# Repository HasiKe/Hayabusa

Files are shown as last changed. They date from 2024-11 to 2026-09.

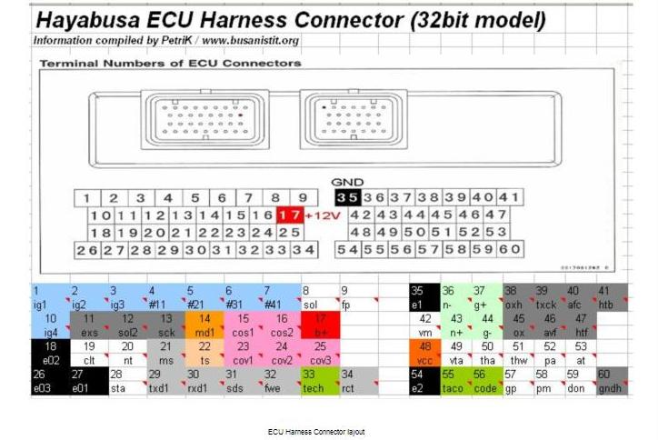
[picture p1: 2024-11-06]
hardware/ECU/docs/Hayabusa ECU 1.jpg

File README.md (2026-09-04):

# Hayabusa

Eigenbau-Motorsteuerung und Umbauprojekte für die Suzuki Hayabusa der ersten
Generation (1999–2007).

Das Repository enthält die Elektronik des Umbaus: Schaltpläne und Layouts der
Steuergeräte, die Firmware, die Abstimmung und die Dokumentation dazu. Die
Speeduino-Firmware ist dabei der Ausgangspunkt, nicht das Ergebnis — Platinen,
Sensorik und die Motorrad-spezifischen Funktionen sind eigene Arbeit.

---

## Inhalt

| Pfad | Inhalt |
|---|---|
| [`hardware/ECU/`](hardware/ECU) | Steuergerät: Schaltplan, Layout, Fertigungsdaten, Gehäuse |
| [`speeduino/`](https://github.com/HasiKe/speeduino/tree/Hayabusa/ECU-R3) | Motorsteuerungs-Firmware und Sensor-Modul-Firmware, Submodul auf den eigenen Fork |
| [`hardware/exhaust-mic/`](hardware/exhaust-mic) | Zweikanalige Tonaufnahme von Motor und Auspuff |
| [`tune/`](tune) | TunerStudio-Projekt [`Hayabusa-R3`](tune/Hayabusa-R3) (generiert aus den Serienkennfeldern in `tune/setup/`) |
| [`docs/`](docs) | Dokumentation und Spezifikationen |

---

## Das Steuergerät

Ersetzt das Seriensteuergerät vollständig. Zweilagige Platine von rund
148 × 112 mm mit einem Teensy 4.1 als Rechenkern, Schaltplanstand
**Revision 3.0 (Entwurf)**.

### Leistungsteil

| Baustein | Aufgabe |
|---|---|
| MC33810 | Einspritzung und Zündung über SPI, vier Kanäle je Pfad |
| 4× ISL9V5036 | Zünd-IGBTs an den Gate-Treibern des MC33810 |
| 3× ZXMS6006 | Low-Side für Kraftstoffpumpe, Lüfter, Starter, Drehzahlmesser, FI-Lampe |
| 2× BTF3050TE | High-Side für Ladedrucksteller und Lambdaheizung, mit Stromfühler |
| DRV8434A | Schrittmotor für den Leerlaufsteller |

### Signalaufbereitung

| Baustein | Aufgabe |
|---|---|
| MAX9926 | Zwei Kanäle Induktivgeber für Kurbelwelle und Nockenwelle |
| TPIC8101 | Klopfsensor mit programmierbarem Bandpass und Integrator |
| LMV324 | Puffer für Lambda, Komparator für den Kippschalter |
| SP720 / BAV199 | Klemmung sämtlicher Sensoreingänge |

### Versorgung und Infrastruktur

| Baustein | Aufgabe |
|---|---|
| LM74700 + SQM120N06 | Verpolschutz als aktive Diode |
| TPS54360B | Abwärtswandler auf 5 V, automotive-tauglich |
| TPS3823 | Externer Watchdog, verriegelt bei Ausfall die Endstufen |
| W25Q32 | SPI-Flash als Kennfeldspeicher |
| MCP2562 | CAN zum Sensor-Modul und zum Cockpit |
| ADXL343 | Beschleunigungssensor, bestückt, softwareseitig ungenutzt |

Vollständige Pinbelegung, Kalibrierhinweise und die offenen Punkte der
Revision 3.0: **[HAYABUSA_ECU_R3.md](https://github.com/HasiKe/speeduino/blob/Hayabusa/ECU-R3/HAYABUSA_ECU_R3.md)**

---

## Firmware

Fork von [Speeduino](https://github.com/speeduino/speeduino), Branch
[`Hayabusa/ECU-R3`](https://github.com/HasiKe/speeduino/tree/Hayabusa/ECU-R3),
eingebunden als Submodul.

```bash
git submodule update --init
cd speeduino && pio run -e teensy41_hayabusa
```

In TunerStudio Board **57 „Gen1 Hayabusa ECU R3"** wählen.

Was über den Serienstand von Speeduino hinausgeht:

- **Vier umschaltbare Kennfeldsätze** für Kraftstoff, Zündung und Ladedruck.
  Auswahl beim Einschalten über Kupplung und Vollgas, Rückmeldung über
  FI-Lampe und Drehzahlmesser.
- **Klopfregelung** mit dem TPIC8101: Konfiguration über SPI,
  Integrationsfenster am Zündfunken, Auswertung über Speeduinos
  Zündrücknahme.
- **Externer Watchdog**, der nur bedient wird, solange die Hauptschleife
  läuft — bleibt sie hängen, fallen Einspritzung und Zündung ab.
- **Motorrad-Ein- und Ausgänge**: Neutral, Kupplung, Gangsensor,
  Kippschalter, FI-Lampe, Lambdaheizung.
- **Kanalzuordnung nach Zündfolge 1-2-4-3** am Serienstecker, der nach
  Zylindern belegt ist.
- **Kennfelder im SPI-Flash** statt in der EEPROM-Emulation des Teensy, die
  für vier Sätze zu klein ist.

---

## Sensor-Modul

Zweite Platine, 120 × 64 mm, eigener STM32G474. Nimmt der Motorsteuerung alles
ab, was langsam ist, und meldet es über CAN.

- vier Abgastemperaturen über MAX31855K-Thermoelementwandler
- Öldruck, Kraftstoffdruck, Abgasdruck, Öltemperatur
- zwei Wassertemperaturen im Ladeluftkühlerkreis
- Quickshifter-Geber
- Regelung des Ladeluftkühler-Lüfters, lokal und damit unabhängig vom CAN-Bus

Firmware, CAN-Protokoll und die Zuordnung zu Speeduinos Eingangskanälen:
[`speeduino/sensor-module/README.md`](https://github.com/HasiKe/speeduino/blob/Hayabusa/ECU-R3/sensor-module/README.md)

---

## Exhaust-Mic

Eigenständiges Projekt: zweikanalige Tonaufnahme von Motor- und
Auspuffgeräuschen. Zwei Mikrofonköpfe mit 135 dBSPL Grenzschalldruck an einem
24-bit-Stereo-ADC, aufgezeichnet von einem ESP32-S3 auf microSD, mit
Zeitstempeln zur Synchronisation mit Videomaterial.

Schaltpläne, Layout, Gehäuse und Firmware entstehen aus Python-Generatoren —
Pinbelegung und Netznamen stehen dadurch nur an einer Stelle.

Eigenes Repository, hier als Submodul eingebunden:
[HasiKe/Exhaust-Mic](https://github.com/HasiKe/Exhaust-Mic)

---

## Stand

| Bereich | Stand |
|---|---|
| Steuergerät, Schaltplan | Revision 3.0 im Entwurf, Revision 1 gefertigt |
| Steuergerät, Firmware | Läuft, auf aktuellem Speeduino-Stand |
| Sensor-Modul, Hardware | Revision 3.0 im Entwurf |
| Sensor-Modul, Firmware | Übersetzt, noch nicht am Fahrzeug erprobt |
| Exhaust-Mic | Schaltplan und Layout fertig, Fertigung offen |
| Grundabstimmung | Erststart-Tune erzeugt (`tune/Hayabusa-R3`), Motor damit noch nicht gelaufen |

Was vor dem ersten Start geprüft werden muss — Trigger-Winkel, Kalibrierungen,
Kanalzuordnung, Polarität des Kippschalters, Klopfschwellen — steht in
[`tune/Hayabusa-R3/README.md`](tune/Hayabusa-R3/README.md),
[HAYABUSA_ECU_R3.md](https://github.com/HasiKe/speeduino/blob/Hayabusa/ECU-R3/HAYABUSA_ECU_R3.md)
und im [README des Sensor-Moduls](https://github.com/HasiKe/speeduino/blob/Hayabusa/ECU-R3/sensor-module/README.md).

---

## Dokumentation

| Dokument | Inhalt |
|---|---|
| [HARDWARE.md](docs/HARDWARE.md) | Platinen, Steckerbelegung, mechanische Daten |
| [SOFTWARE.md](docs/SOFTWARE.md) | Firmware-Aufbau, Build, Codestruktur |
| [INSTALLATION.md](docs/INSTALLATION.md) | Einbau, Verkabelung, Inbetriebnahme |
| [TUNING.md](docs/TUNING.md) | Kennfelder, Kalibrierung, Abstimmung |
| [PROJECT_STRUCTURE.md](docs/PROJECT_STRUCTURE.md) | Aufbau des Repositories |
| [CHANGELOG.md](CHANGELOG.md) | Versionshistorie |

Externe Quellen: [Speeduino-Wiki](https://wiki.speeduino.com) ·
[Speeduino-Forum](https://speeduino.com/forum) ·
[TunerStudio](http://tunerstudio.com)

---

## Lizenz

Die Firmware im Submodul steht unter GPL v3, wie Speeduino selbst. Hardware
und Dokumentation stehen unter CC BY-SA 4.0. Fremdsoftware liegt nicht im
Repository, sondern wird bei Bedarf aus der jeweiligen Quelle geladen.

## Haftungsausschluss

Ein selbst gebautes Steuergerät greift in Zündung und Kraftstoffzufuhr ein.
Fehler darin führen zu Motorschaden oder zum Ausfall während der Fahrt. Der
Nachbau erfolgt auf eigene Verantwortung, und im Geltungsbereich der StVZO
erlischt mit solchen Eingriffen die Betriebserlaubnis, solange kein Gutachten
vorliegt.

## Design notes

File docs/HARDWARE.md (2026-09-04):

# Hardware-Dokumentation

Steuergerät **Gen1 Hayabusa ECU Rev 3.0** (Schaltplan und Layout in `hardware/ECU/`,
Fertigungsdaten in `hardware/ECU/output/pcbway/`, Stückliste in `hardware/ECU/bom/`).
Die Rev 1 auf Dropbear-Basis ist Geschichte; dieses Dokument beschreibt nur die Rev 3.

## Überblick

| Parameter | Wert |
|---|---|
| Rechenkern | Teensy 4.1 (NXP i.MX RT1062, 600 MHz), USB über J2 auf die Device-Pads |
| Platine | zweilagig, ca. 148 × 112 mm, drei M3-Befestigungen, Gehäuse in `hardware/ECU/case/` (Fusion 360, STL, Kühlkörper) |
| Stecker | J2 = TE 6437288-3, 60-polig, Belegung nach dem Serien-Steuergerät (`hardware/ECU/docs/Pinout.ods`, Blatt `Pinout_ori_ECU`) |
| Endstufen | MC33810 (SPI, GPGD-Modus) → 4 Low-Side-Injektortreiber, 4 Gate-Treiber für ISL9V5036-IGBTs |
| Kleinlasten | 3× ZXMS6006 Low-Side (Kraftstoffpumpe, Lüfter, Starter, Drehzahlmesser, FI-Lampe, Spare), 2× BTF3050TE High-Side (Ladedrucksteller, Lambdaheizung) |
| Leerlaufsteller | DRV8434A Schrittmotortreiber (Serienmotor hat keinen, Ausgang ungenutzt) |
| Kurbel/Nocke | MAX9926, zwei VR-Kanäle |
| Klopfen | TPIC8101 über SPI, Integratorausgang an A17 |
| Lambda | LMV324-Puffer 0–3,3 V, kein Breitband-Frontend (Innovate LC-2 extern) |
| Versorgung | LM74700 + SQM120N06 (Verpolschutz), TPS54360B (5 V Buck), LD1117S33 (3,3 V), TPS7B6950-Q1 (VDDA, Sensor-5 V an J2.48) |
| Watchdog | TPS3823, WDI von D3, RESET verriegelt über 74LVC1G00 mit D2 den MC33810-OUTEN |
| Speicher | W25Q32 SPI-Flash als Kennfeldspeicher (8184 Byte emuliertes EEPROM, 4 Kennfeldsätze) |
| Kommunikation | MCP2562 CAN (CAN1, 500 kbit/s) zum Sensor-Modul, Serial1 auf J1 |
| Sonstiges | ADXL343 bestückt, softwareseitig ungenutzt |

## Teensy-Belegung

Aus der Rev-3.0-Netzliste, identisch mit `speeduino/HAYABUSA_ECU_R3.md`.

| Teensy | Netz / Baustein | Firmware |
|---|---|---|
| D0 / D1 | J1 | Serial1 (sekundäre Schnittstelle) |
| D2 | 74LVC1G00 → MC33810 OUTEN | Ausgabefreigabe, Fuel- und Spark-Kill |
| D3 | TPS3823 WDI | Watchdog |
| D4 | J2.20 | Neutralschalter |
| D5 | IC3.1 → J2.9 | Kraftstoffpumpe |
| D6 | W25Q32 CS | Kennfeldspeicher |
| D7 | ADXL343 CS | ungenutzt |
| D8 | IC3.2 → J2.55 | Drehzahlmesser |
| D9 | DRV8434A nFAULT + BTF3050 Status | Treiberfehler, aktiv low |
| D10 | MC33810 CS | Injektor- und Zündtreiber |
| D11 / D12 / D13 | MOSI / MISO / SCLK | gemeinsamer SPI-Bus |
| D20 | MAX9926 COUT1 | Kurbelwelle |
| D21 | MAX9926 COUT2 | Nockenwelle |
| D22 / D23 | MCP2562 | CAN1 |
| D24 | U13 → J2.30 | Ladedrucksteller |
| D25 | U14 → J2.46 | Lambdaheizung (bei LC-2 offen lassen) |
| D26 | IC2.2 → J2.28 | Starter-Ausgang, frei für programmierbaren Ausgang |
| D27 | IC2.1 → J2.42 | FI-Lampe |
| D28 | IC4.2 → J2.47 | Spare-Ausgang |
| D29 | IC4.1 → J2.29 | Lüfter |
| D30 / D31 / D32 | DRV8434A STEP / DIR / ENABLE+nSLEEP | Schrittmotor |
| D33 | J2.19 | Kupplung: Launch-Eingang und Kennfeldwahl |
| D34 | LMV324-Komparator | Kippschalter |
| D35 | J2.60 | Spare-Digitaleingang, als VSS gemappt |
| D36 / D37 | TPIC8101 INT/HOLD / CS | Klopfsensor-IC |
| A0 / A1 / A2 | J2.58 / J2.52 / J2.49 | MAP / Baro / TPS |
| A3 | J2.38 über LMV324 | Lambda |
| A4 / A5 | J2.50 / J2.51 | IAT / CLT |
| A14 / A15 | J2.39 / 12V-PROT-Teiler | Flex / Batteriespannung |
| A16 | J2.57 | Gangsensor |
| A17 | TPIC8101 OUT | Klopfintegrator |

## Steckerbelegung J2

Die Nummern entsprechen dem Serien-Steuergerät, der Serienkabelbaum passt. Nur die
Pins mit Funktion in der Rev 3 sind gelistet.

| Pin | Serie | Rev 3 | Anmerkung |
|---|---|---|---|
| 1 | Spule Zyl. 1 | IGN1 (GD0, Q2) | Kanalzuordnung siehe unten |
| 2 | Spule Zyl. 2 | IGN2 (GD1, Q1) | |
| 3 | Spule Zyl. 3 | IGN4 (GD2, Q3) | Speeduino-Kanal 4 = vierter in der Zündfolge |
| 10 | Spule Zyl. 4 | IGN3 (GD3, Q4) | Speeduino-Kanal 3 = dritter in der Zündfolge |
| 7 | Düse Zyl. 1 | INJ1 (OUT0) | |
| 6 | Düse Zyl. 2 | INJ2 (OUT1) | |
| 5 | Düse Zyl. 3 | INJ4 (OUT2) | |
| 4 | Düse Zyl. 4 | INJ3 (OUT3) | |
| 8, 31, 32, 45 | 8: VC-Solenoid | Schrittmotor A1/A2/B1/B2 | ungenutzt |
| 9 | Kraftstoffpumpe | Low-Side D5 | |
| 17 | Zündung 12 V | 12V-PROT | Versorgung |
| 18, 26, 27, 35 | Masse | GND | |
| 19 | Starterrelais-Eingang | Kupplung (D33) | 12 V bei Starter, 0 V bei gezogener Kupplung; siehe Befund 1 |
| 20 | Neutral | D4 | 0 V in Neutral |
| 22 | Diagnose | DIAG-IN | nicht verbunden |
| 28 | Starterrelais | Starter-Ausgang D26 | |
| 29 | – | Lüfter D29 | |
| 30 | – | Ladedrucksteller D24 | |
| 36 / 43 | Kurbel − / + | MAX9926 Kanal 1 | VR |
| 37 / 44 | Nocke + / − | MAX9926 Kanal 2 | VR |
| 38 | – | Lambda 0–3,3 V | LC-2 Analogausgang 1 |
| 39 | – | Flex | 2,2 kΩ Pull-up, ungenutzt |
| 42 | Kraftstoff 12 V | FI-Lampe D27 | |
| 46 | – | Lambdaheizung D25 | offen lassen |
| 47 | – | Spare-Ausgang D28 | |
| 48 | Sensor 5 V | VDDA | TPS7B6950, Polyfuse 150 mA |
| 49 | TPS | A2 | |
| 50 | Ansauglufttemperatur | A4 | |
| 51 | Wassertemperatur | A5 | |
| 52 | Atmosphärendruck | A1 (Baro) | im Tune nicht genutzt |
| 53 | – | Spare-Analog | Beschaltung vorhanden, kein ADC-Pin (Befund 2) |
| 54 | Sensormasse | GNDA | |
| 55 | Drehzahlmesser | D8 | |
| 57 | Gangsensor | A16 | 1 kΩ Vorwiderstand, Schwellen in der Firmware |
| 58 | Saugrohrdruck | A0 (MAP) | Serien-IAP 18590-81A00 |
| 59 | Kippschalter | Komparator → D34 | |
| 60 | – | Spare-Digital D35 | |
| 14 / 15 | – | CAN H / L | Sensor-Modul, Cockpit |
| 16 / 24 | Diagnose | USB VBUS / USB GND | USB-Daten siehe Blatt Comms |

### Kanal- und Zylinderzuordnung

Speeduino feuert seine Kanäle in der Zündfolge (0°, 180°, 360°, 540°), der Stecker ist
nach Zylindernummer belegt, die Zündfolge ist 1-2-4-3. Die Firmware legt deshalb Kanal 3
auf Zylinder 4 und Kanal 4 auf Zylinder 3 (`getHayabusaR3Mapping()`); am Kabelbaum wird
nichts getauscht. Zylinder 1 liegt links auf der Generatorseite.

## Analoge Eingangsbeschaltung

| Eingang | Beschaltung | Folge für die Kalibrierung |
|---|---|---|
| MAP, Baro, TPS, Gangsensor | 470 Ω → 100 nF → Teiler 12 k/20 k (0,625) → 10 nF → BAV199 an 3V3/GND | ADC-Vollausschlag = 3,3 V / 0,625 = 5,28 V am Sensor. `mapMax` entsprechend rechnen (Serien-IAP: 10 / 142 kPa) |
| IAT, CLT | Pull-up 2,49 kΩ an **3V3** → 470 Ω → BAV199 | ratiometrisch zur ADC-Referenz, TunerStudio-Bias 2490 Ω exakt |
| Lambda | LMV324-Folger an 3,3 V | Sensor 0–3,3 V, LC-2 Ausgang entsprechend programmieren |
| Batterie | 47 k/10 k von 12V-PROT | Vollausschlag 18,8 V; Firmware skaliert für Board 57 |
| Flex | 2,2 kΩ Pull-up 3V3, 1 kΩ + 1 nF + BAV199 | Frequenzeingang |
| Neutral, Kupplung, Spare-Digital | Teiler 10 k/10 k zwischen Steckerpin und 3V3 (R78/R80, R71/R73, R79/R81), 100 nF, BAV199 | geschlossener Schalter ergibt nur 1,65 V, siehe Befund 1 |
| Kippschalter | LMV324 als Komparator, Schwelle 1,2 V nach Teiler 0,5 | Polarität am Fahrzeug prüfen |

Kurbel und Nocke: MAX9926 datenblattkonform, differenziell bis zum IC, Serienwiderstände
vor den Teensy-Pins, Eingangsfilter 470 pF. Trigger-Flanke RISING.

## Klopfsensor

TPIC8101 am SPI, Konfiguration beim Start durch die Firmware: 4-MHz-Resonator, Kanal 1,
Bandpass Index 39 (6,37 kHz, erste Umfangsmode einer 81-mm-Bohrung), Verstärkung Index 14,
Integrator Index 18 (200 µs). Fenster öffnet mit dem Zündfunken, schließt aus dem
1-kHz-Dienst. Bosch 0 261 231 173 am Block zwischen Zylinder 2 und 3 geplant, noch nicht
verbaut. In TunerStudio Klopfmodus **Analog**, der Pin wird ignoriert.

## Befunde der Rev 3.0

Aus `speeduino/HAYABUSA_ECU_R3.md`, hardwareseitig noch offen:

1. **Schalteingänge erreichen keinen gültigen Low-Pegel.** Neutral (D4), Kupplung (D33)
   und Spare-Digital (D35) liegen über 10 k/10 k zwischen Stecker und 3V3; geschlossener
   Schalter ergibt 1,65 V, Teensy VIL ist 0,9 V. Kennfeldwahl und Launch-Eingang hängen
   davon ab. Abhilfe: unteren Zweig nach Masse oder 10 k in Serie mit 100 k Pull-up.
2. **Spare-Analog (J2.53) endet an keinem ADC-Pin.**
3. **Kein Startanforderungs-Eingang**, deshalb keine Neutral/Kupplungs-Verriegelung; der
   Starter-Ausgang bleibt frei nutzbar.

Unkritisch: MC33810 FB0..3 und RSP werden im GPGD-Modus nicht benutzt; die GIN-Pins sind
nicht angeschlossen, die Spulen werden über SPI geschaltet.

## Stückliste und Fertigung

- `hardware/ECU/bom/ECU-BOM.csv` (107 Positionen) und `Sensor-Modul-BOM.csv` (46), alle
  Bauteile mit Hersteller- und DigiKey-Nummer.
- PCBWay-Pakete (Gerber, CPL, BOM) in `hardware/ECU/output/pcbway/<board>/`.
- Last-Time-Buy-Teile: MCZ33810EK und ZXMS6006DT8TA (2027), Vorrat kaufen.
- Bestellungen und Fahrzeugteile: `docs/BESTELLUNG.ods`.

## Sensor-Modul

Zweite Platine, 120 × 64 mm, STM32G474, Rev 3.0. Vier Abgastemperaturen (MAX31855K),
Öl-, Kraftstoff- und Abgasdruck, Öltemperatur, zwei Wassertemperaturen im
Ladeluftkühlerkreis, Quickshifter-Geber, lokale Regelung des Ladeluftkühler-Lüfters.
Meldet über CAN an die ECU. Schaltplan `hardware/ECU/sensor-module.kicad_sch`, Firmware
und CAN-Protokoll in `speeduino/sensor-module/`.

## Externe Sensorik am Fahrzeug (1999)

| Sensor | Teil | Kennwerte |
|---|---|---|
| Saugrohrdruck | Serien-IAP 18590-81A00 an J2.58 | ≈ 3,6 V bei 100 kPa, Näherung P ≈ 25·V + 10 kPa |
| TPS | Serie | ≈ 1,1 V geschlossen, 4,3 V offen |
| Kühlmittel | Serien-NTC | 2,3–2,6 kΩ bei 20 °C, 811 Ω bei 50 °C, 318 Ω bei 80 °C |
| Ansaugluft | Serien-NTC | 2,2–2,7 kΩ bei 20 °C |
| Kurbelwelle | VR im Generatordeckel, 8 Zähne gleichmäßig auf dem Generatorrotor | 180–280 Ω |
| Nockenwelle | VR auf dem Ventildeckel links, ein Stift auf der Einlassnocke | 0,9–1,3 kΩ |
| Lambda | Innovate LC-2 + Bosch LSU 4.9 | Analogausgang 1 auf 0–3,3 V programmiert |
| Düsen | 15710-24F00, Keihin, hochohmig 11–16 Ω | ≈ 257 cc/min bei 3 bar (Annahme) |
| Spulen | Denso 33410-24F00 Stabspulen ohne Igniter | 0,8–1,2 Ω primär |

---

**Version**: 4.0
**Stand**: September 2026

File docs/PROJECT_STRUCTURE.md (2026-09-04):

# Projektstruktur

## Verzeichnisübersicht

```
hayabusa/
├── README.md                     Projektübersicht
├── CHANGELOG.md                  Versionshistorie
├── .gitmodules                   drei Submodule
│
├── docs/                         Dokumentation
│   ├── HARDWARE.md               Steuergerät Rev 3, Stecker, Eingangsbeschaltung
│   ├── SOFTWARE.md               Firmware-Fork, Board 57, TunerStudio, Generator
│   ├── INSTALLATION.md           Einbau, Verkabelung, Inbetriebnahme
│   ├── TUNING.md                 Kennfelder, Kalibrierung, Abstimmung
│   ├── PROJECT_STRUCTURE.md      diese Datei
│   ├── BESTELLUNG.ods            Bestell- und Teilelisten
│   ├── Berechnungen.ods          Auslegungsrechnungen
│   ├── Drehmoment.pdf            Anzugsdrehmomente, dazu ARP- und Wössner-Anleitungen
│   ├── Speeduino_manual.pdf      Speeduino-Handbuch
│   └── explosionszeichnung/      Suzuki-Ersatzteilzeichnungen
│
├── hardware/                     nur die beiden Elektronikprojekte
│   ├── ECU/                      Steuergerät und Sensor-Modul (KiCad)
│   │   ├── *.kicad_*             Schaltpläne und Layouts beider Platinen
│   │   ├── bom/                  Stücklisten (CSV): ECU 107, Sensor-Modul 46 Positionen
│   │   ├── case/                 Gehäuse (Fusion 360, STL, Kühlkörper)
│   │   ├── datasheets/           Datenblätter der Hauptbausteine
│   │   ├── docs/                 Pinout.ods (Serienstecker), Kabelplan, Altunterlagen
│   │   ├── lib/                  Symbole, Footprints, 3D — teensy.pretty als Submodul
│   │   └── output/               Schaltplan-PDFs, Gerber, STEP; Fertigungspakete in pcbway/
│   └── exhaust-mic/              Submodul HasiKe/Exhaust-Mic
│
├── speeduino/                    Submodul HasiKe/speeduino, Branch Hayabusa/ECU-R3
│   ├── speeduino/                Firmware, src/hayabusa/ für die Board-Funktionen
│   ├── reference/speeduino.ini   TunerStudio-Definition
│   ├── sensor-module/            STM32G474-Firmware des Sensor-Moduls
│   ├── HAYABUSA_ECU_R3.md        Firmware-Notizen zur Rev 3
│   └── platformio.ini            Umgebung teensy41_hayabusa
│
└── tune/
    ├── Hayabusa-R3/              TunerStudio-Projekt (generiert)
    │   ├── CurrentTune.msq
    │   ├── README.md             Herkunft, Checkliste vor dem ersten Start
    │   ├── projectCfg/           mainController.ini (Kopie der Fork-INI), project.properties
    │   └── tools/                gen_tune.py und Helfer
    └── setup/                    Serienkennfelder (maps.ods), ECUeditor-Screenshot
```

## Architektur

### Hardware

```
┌─────────────────────────────────────────────────────────────┐
│                        HARDWARE                              │
├─────────────────────────────────────────────────────────────┤
│  ┌─────────────┐    ┌─────────────┐    ┌─────────────┐      │
│  │  Sensoren   │    │  ECU Board  │    │  Aktuatoren │      │
│  │             │    │             │    │             │      │
│  │  TPS        │◄──►│  Teensy 4.1 │◄──►│  Injektoren │      │
│  │  MAP        │    │  Speeduino  │    │  Zündung    │      │
│  │  CLT/IAT    │    │  MC33810    │    │  Kraftstoff │      │
│  │  O2 (LC-2)  │    │  CAN        │    │  Lampe/Tach │      │
│  │  RPM/Cam    │    │             │    │             │      │
│  └─────────────┘    └─────────────┘    └─────────────┘      │
└─────────────────────────────────────────────────────────────┘
```

### Software

```
┌─────────────────────────────────────────────────────────────┐
│                      SOFTWARE STACK                          │
├─────────────────────────────────────────────────────────────┤
│  ┌─────────────┐    ┌─────────────┐    ┌─────────────┐      │
│  │ TunerStudio │    │  Speeduino  │    │  Hardware   │      │
│  │             │    │  Firmware   │    │  Treiber    │      │
│  │  GUI        │◄──►│  Engine     │◄──►│  PWM/ADC    │      │
│  │  Maps       │    │  Logic      │    │  Interrupts │      │
│  │  Logging    │    │  Scheduler  │    │  Timer      │      │
│  │  Monitoring │    │  Safety     │    │  Serial     │      │
│  └─────────────┘    └─────────────┘    └─────────────┘      │
└─────────────────────────────────────────────────────────────┘
```

## Dateitypen

### Hardware

| Typ | Beschreibung | Software |
|-----|---|---|
| .kicad_pro, .kicad_sch, .kicad_pcb | PCB Design | KiCad |
| .gbr, .drl | Gerber/Drill für Produktion | GerbView |
| .step, .stp | 3D CAD | FreeCAD, SolidWorks |

### Software

| Typ | Beschreibung | Software |
|-----|---|---|
| .ino, .cpp, .h | Firmware | PlatformIO |
| .py | Tune-Generator | Python 3, odfpy |
| .msq | TunerStudio Tune | TunerStudio |
| .ini | ECU Definition | TunerStudio |

### Dokumentation

| Typ | Beschreibung |
|-----|---|
| .md | Markdown Dokumentation |
| .ods | Kalkulationen, BOMs |
| .pdf | Handbücher, Datenblätter |

## Entwicklung

### Voraussetzungen

**Hardware:**
- KiCad 10 (Dateien der Rev 3), Fusion 360 für das Gehäuse

**Software:**
- PlatformIO
- TunerStudio MS Ultra
- Python 3 mit odfpy (Tune-Generator)
- Git

### Repository klonen

```bash
# Mit Submodules
git clone --recursive https://github.com/HasiKe/Hayabusa.git

# Submodules aktualisieren
git submodule update --init --recursive

# Pull mit Submodules
git pull --recurse-submodules
```

### Build-Prozess

```bash
# Firmware kompilieren und flashen
cd speeduino
pio run -e teensy41_hayabusa
pio run -e teensy41_hayabusa -t upload

# Tune neu erzeugen
python3 tune/Hayabusa-R3/tools/gen_tune.py
```

## Commit-Konventionen

Kurze, sachliche Betreffzeile ohne Präfix: im Hauptrepository deutsch, im Firmware-Fork
englisch. Der Text erklärt das Warum. Keine Werkzeug- oder Sitzungsverweise.

---

**Version**: 4.0
**Stand**: September 2026

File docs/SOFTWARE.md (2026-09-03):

# Software-Dokumentation

## Firmware

Fork von [Speeduino](https://github.com/speeduino/speeduino), Stand 2025.04-dev
(TunerStudio-Signatur `speeduino 202504-dev`).

| Parameter | Wert |
|---|---|
| Repository | [HasiKe/speeduino](https://github.com/HasiKe/speeduino), Branch `Hayabusa/ECU-R3` (lokal `Hayabusa/ECU-R3-v2`) |
| Einbindung | Submodul `speeduino/` |
| Board | Teensy 4.1, TunerStudio-Board **57 „Gen1 Hayabusa ECU R3"** |
| PlatformIO-Umgebung | `teensy41_hayabusa` (`-DUSE_SPI_EEPROM -DSPI_FLASH_ATOMIC_TRANSFERS -DHAYABUSA_ECU_R3`) |
| Lizenz | GPL v3 |
| Notizen | `speeduino/HAYABUSA_ECU_R3.md` |

```bash
git submodule update --init
cd speeduino
pio run -e teensy41_hayabusa            # bauen
pio run -e teensy41_hayabusa -t upload  # flashen
```

Nach dem ersten Brennen eines Tunes mit Board 57 die ECU aus- und einschalten: Pinmapping,
MC33810-Initialisierung und Watchdog werden nur beim Start übernommen.

## Was der Fork gegenüber Speeduino ergänzt

Alles in `speeduino/speeduino/src/hayabusa/` und nur aktiv mit `HAYABUSA_ECU_R3` und
Board 57.

| Funktion | Umsetzung |
|---|---|
| Pinmapping | `src/pins/pinMapping.cpp`, `getHayabusaR3Mapping()`: alle Pins fest, Injektoren und Spulen über MC33810-Bits; Kanal 3 → Zylinder 4, Kanal 4 → Zylinder 3 (Zündfolge 1-2-4-3) |
| Kennfeldspeicher | W25Q32 statt EEPROM-Emulation (`board_teensy41.cpp`): 264 Sektoren × 31 Byte = 8184 Byte, Standardlayout unverändert, Zusatztabellen ab Adresse 4096 |
| Watchdog | `hayabusa_r3.cpp`: TPS3823 wird aus dem 1-kHz-Timer bedient, aber nur wenn die Hauptschleife seit dem letzten Kick gelaufen ist; während `initialiseAll()` bedingungslos |
| Ausgabefreigabe | D2 mit Watchdog-Reset über NAND auf MC33810-OUTEN; Kippschalter (D34, 500 ms entprellt) nimmt die Freigabe weg |
| Klopfen | `knock_tpic8101.cpp`: TPIC8101 per SPI konfiguriert, Fenster am Zündfunken, Wert auf 2-ms-Fenster normiert an Speeduinos analoge Klopfrücknahme; Build-Flags `HAYABUSA_KNOCK_BANDPASS_INDEX`, `_GAIN_INDEX`, `_INTEGRATOR_INDEX`, `_WINDOW_US` |
| Motorrad-I/O | Neutral, Kupplung, Gangsensor (Schwellen `HAYABUSA_GEAR_THRESHOLDS`), Kippschalter (`HAYABUSA_TIPOVER_INVERTED`), FI-Lampe, Lambdaheizung (3 s nach Drehzahl > 0 an), Treiberfehler-Eingang |
| Kennfeldsätze | vier Sätze Kraftstoff/Zündung/Ladedruck; Satz 1 = Standardtabellen, Satz 2 = Speeduinos Zweittabellen, Sätze 3/4 = Seiten 16–21; Auswahl in `mapselection.cpp` (`speeduino.ino`: `getActiveFuelTable()`) |
| Batteriespannung | `sensors.cpp readBat()`: Vollausschlag 18,8 V für den 47 k/10 k-Teiler (`HAYABUSA_R3_BATTERY_FULL_SCALE_10`) |
| SPI-Bus | vier Teilnehmer mit eigenen Transaktionen; Flash und Klopf-IC sperren Interrupts, solange ihr CS aktiv ist |

### Kennfeldsatz wählen

Zündung einschalten mit Vollgas und gezogener Kupplung. FI-Lampe blinkt die Satznummer,
Drehzahlmesser zeigt Satz × 1000. Jeder Kupplungszug schaltet weiter (4 → 1), drei
Sekunden gehalten bestätigt (nach mindestens einem Loslassen), zehn Sekunden ohne
Eingabe = Satz 1. Die Auswahl wird nicht gespeichert. Satz 2 schaltet Speeduinos
Zweittabellen-Blending ab; `fuel2Mode` und `spark2Mode` bleiben Aus.

Voraussetzung ist ein gültiger Low-Pegel am Kupplungseingang, siehe Befund 1 in
[HARDWARE.md](HARDWARE.md).

## TunerStudio

- INI: `speeduino/reference/speeduino.ini`. Im Projekt unter *Project Properties →
  Settings* „Hayabusa multi map switching = Enabled" wählen, sonst fehlen die Seiten
  16–21. Nicht mit dem seriellen Kompatibilitätsmodus kombinierbar.
- Setting-Groups des Projekts: `mcu_teensy`, `HAYABUSA_MULTIMAP`, `CELSIUS`, `AFR`,
  `pressure_bar`, `enablehardware_test`, `resetcontrol_standard`.
- Korrekturen der INI auf diesem Branch (September 2026): `ignTrim1..8` von Seite 6 (dort
  überschrieben sie `airDenRates`, `boostFreq`, `vvtFreq`, `idleFreq` und das Launch-Byte)
  auf Seite 13 Offset 42; Load-Achsen der Kennfeldsätze 3/4 folgen dem Last-Algorithmus
  statt fester kPa-Skalierung; `boostTable3/4` mit Skalierung 2,0; `unused0_126` auf
  Bit 0–1.
- Klopfmodus **Analog**; Pin-Einstellung wird auf diesem Board ignoriert.
- Kalibrierungen (Thermistoren, AFR-Sonde, TPS) liegen im Kennfeldspeicher, nicht in der
  .msq. Sie müssen nach jedem Neubeschreiben des Flashs erneut gesendet werden.

## Tune-Projekt und Generator

`tune/Hayabusa-R3/` (siehe dortiges README): `CurrentTune.msq`,
`projectCfg/mainController.ini` (Kopie der Fork-INI), `project.properties`,
`tools/gen_tune.py`. Das Tune wird generiert:

```bash
python3 tune/Hayabusa-R3/tools/gen_tune.py
python3 tune/Hayabusa-R3/tools/dumptables.py tune/Hayabusa-R3/CurrentTune.msq veTable advTable1
```

- `stockmaps.py` liest die Serienkennfelder aus `tune/setup/maps.ods` (Blätter `VE_org`,
  `IGN_org`), korrigiert die Tippfehler der Drehzahlachsen und interpoliert bilinear.
- `iniparse.py` liest die INI mit `#if`-Auswertung; `gen_tune.py` prüft jede Konstante
  gegen Optionsliste, Bereich und Auflösung und schreibt alle 21 Seiten.
- Parameter (Düsen, VE-Skalierung, Zündrücknahme, Trigger, Dwell, Begrenzer) im Dict `P`,
  Einzelwerte im Dict `E`. Änderungen dort, nicht in der .msq von Hand.

## Code-Orientierung

```
speeduino/speeduino/
├── speeduino.ino                 Hauptschleife, getActiveFuelTable()/getActiveIgnitionTable()
├── src/hayabusa/hayabusa_r3.*    Watchdog, OUTEN, Schalter, Gangsensor, Lampe, Heizung
├── src/hayabusa/knock_tpic8101.* Klopf-IC
├── src/hayabusa/mapselection.*   Kennfeldwahl beim Einschalten
├── src/pins/pinMapping.cpp       getHayabusaR3Mapping() (Board 57)
├── acc_mc33810.cpp               MC33810-Treiber, übernimmt die Bit-Arrays aus dem Pinmapping
├── board_teensy41.*              SPI-Flash als EEPROM
├── storage.cpp / pages.cpp       Seiten 16–21 ab Adresse 4096
├── decoders.cpp                  Dual-Wheel-Decoder (8 Zähne + Nockenpuls)
├── sensors.cpp                   readBat() mit Board-57-Skalierung
└── fuel_calcs.cpp                reqFuel = Kraftstoff je Zylinder und Arbeitsspiel bei VE 100 %
speeduino/sensor-module/          STM32G474-Firmware des Sensor-Moduls, CAN-Protokoll im README
speeduino/reference/speeduino.ini TunerStudio-Definition
```

## Offene Punkte

- Kippschalter-Polarität am Fahrzeug prüfen (`HAYABUSA_TIPOVER_INVERTED`); falsch
  gepolt schaltet die Firmware während der Fahrt ab.
- Gangsensor-Schwellen kalibrieren (`hayabusaStatus.gearRaw` beobachten).
- Klopfparameter gegen eine Klopfaufzeichnung prüfen, bevor die Rücknahme scharf ist.
- `hayabusaStatus` (umgekippt, Freigabe, Treiberfehler, Gang) ist in TunerStudio nicht
  sichtbar; ein Statusbyte in den Ausgabekanälen wäre sinnvoll.
- Sensor-Modul-Firmware übersetzt, am Fahrzeug nicht erprobt; CAN-Eingänge im Tune Aus.

---

**Version**: 4.0
**Stand**: September 2026

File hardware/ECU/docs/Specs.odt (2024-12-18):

General Engine info
Hubraum | 1.299 cm³
Bohrung x Hub | 81 mm x 63 mm
Verdichtung | 11:1
Leistung | 175 PS (129kW) bei 9.800 U/min
Drehmoment | 138 Nm bei 7.000 U/min
Getriebe | 6 Gang
Kraftstoffsystem | Elektronisch Doppel-Einspritzung
Zündreihenfolge | 1-2-4-3

Zündspule
Resistance Primary | 1,0 – 1,9 Ohm
Resistance Secondary | 10,0 – 16,2 kOhm
Typ | 2-Draht Coil-on-Plug (COP)
Anzahl | 4 (eine pro zylinder)
Betriebsspannung | 12V
Steuerung | Low-Side-Schaltung
Dwell-Time | 2,0 – 2,5 ms
Injektoren
Typ | Elektronische Mehrpunkt-Kraftstoffeinspritzung
Anzahl | 4 (einer pro Zylinder)
Einspritzung | Saugrohreinspritzung
Bauart | Hochohmige Einspritzventile
Wiederstand | 12 – 16 Ohm
Druchfluss | 240 – 260 cc/min (bei 3 bar)
Betriebsspannung | 12V
Steuerung | Low-Side-Schaltung
Drosselklappe (TPS)
Typ | Induktiver Sensor (VR)
Signalbereich | 0,5 – 4,5 V
Kurbelwellensensor
Typ | Induktiver Sensor (VR)
Zahnrad | 24-2 Zahnrad
Nockenwellensensor
Typ | Hall-Effect-Sensor

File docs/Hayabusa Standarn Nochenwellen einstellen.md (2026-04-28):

## 🧪 Messvorgang (Einlass als Beispiel)

### 1. OT exakt bestimmen

Nicht nach Markierung gehen → **wirklich messen!**
(z. B. mit Kolbenstopper oder Messuhr)

---

### 2. Ventilbewegung messen

Messuhr auf Einlassventil (oder Tassenstößel)

Jetzt drehst du die Kurbelwelle:

#### ➤ Punkt A (Öffnen)

* Ventil hebt sich auf **1,27 mm**
* Winkel ablesen → z. B. **10° vor OT (BTDC)**

#### ➤ Punkt B (Schließen)

* Ventil fällt wieder auf **1,27 mm**
* Winkel ablesen → z. B. **40° nach UT (ABDC)**

---

## Berechnung (wichtig!)

Jetzt rechnest du den **Lobe Center (LC)**:

Formel für Einlass:
[
LC = \frac{(Öffnung + Schließung + 180)}{2}
]

👉 Beispiel:

* Öffnung: 10° BTDC → **10**
* Schließen: 40° ABDC → **40**

[
LC = \frac{(10 + 40 + 180)}{2} = 115°
]

---

##  Zielwert

Bei der Suzuki Hayabusa Gen 1 typisch (je nach Setup):

* Einlass: ca. **105–110°**
* Auslass: ca. **108–112°**

👉 115° wäre z. B. **zu spät (retarded)**

---

##  Einstellen mit Langlöchern

Jetzt kommt der praktische Teil:

* **LC zu groß (z. B. 115°)** → Nocke **vorstellen (advance)**
* **LC zu klein (z. B. 100°)** → Nocke **zurückstellen (retard)**

👉 Faustregel:

* Nockenrad **gegen Drehrichtung → advance**
* Mit Drehrichtung → retard
  (immer prüfen, weil je nach Seite/Ansicht verwirrend!)

---

## 🔁 Wiederholen

* Nach jeder Änderung:

  * wieder messen
  * neu rechnen
* Bis du deinen Zielwert triffst

---

## ⚠️ Typische Fehler

* ❌ OT nicht exakt → alles falsch
* ❌ falsche mm (nicht exakt 1,27 mm)
* ❌ Ventilspiel verfälscht Messung
* ❌ Grad-Scheibe verrutscht

---

## 💡 Pro Tipp

Viele Tuner gehen leicht aggressiver:

* Einlass z. B. **104–106° → mehr Punch unten/mittel**
* Auslass etwas später → bessere Drehzahl

---

Wenn du willst, rechne ich dir **deine gemessenen Werte direkt aus** und sag dir exakt, wie viel Grad du am Nockenrad drehen musst 👍

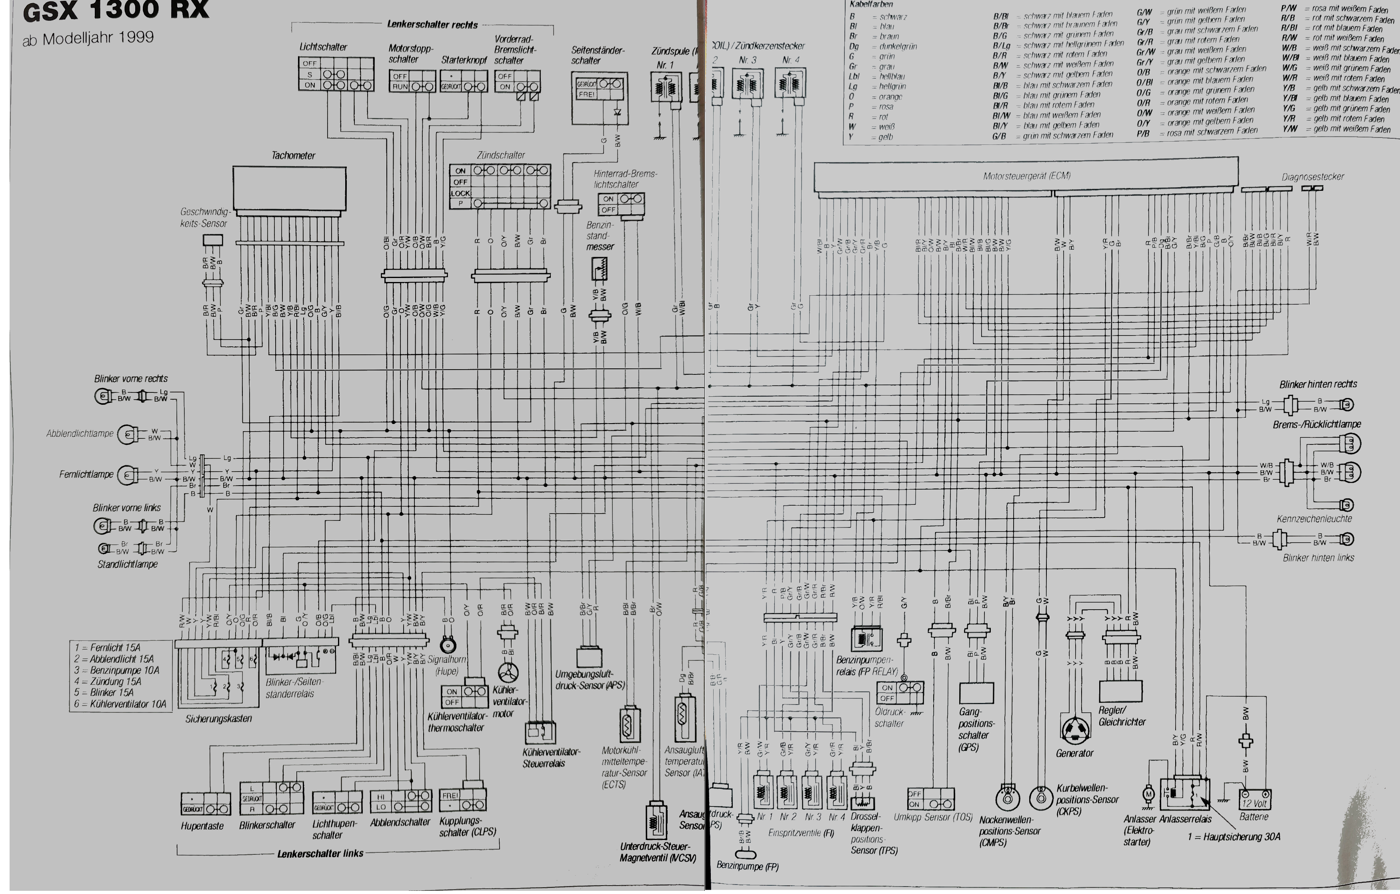
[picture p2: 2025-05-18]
hardware/ECU/docs/Kabelplan.png

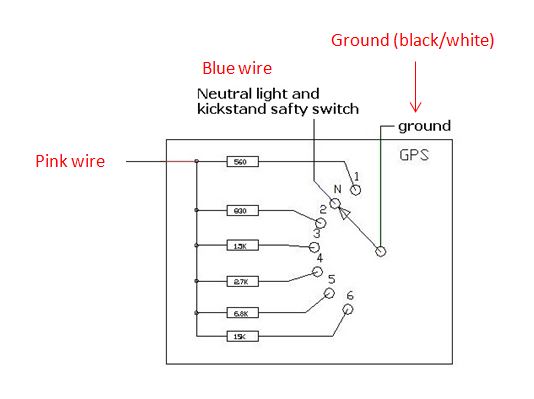
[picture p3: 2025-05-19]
hardware/ECU/docs/GPS.JPG

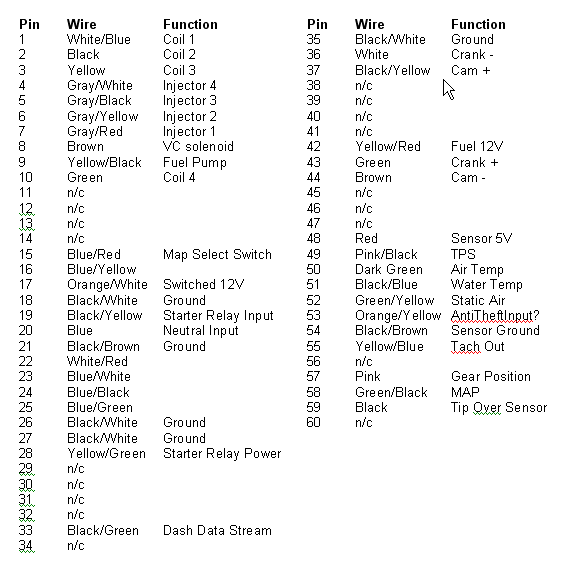
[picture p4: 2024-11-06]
hardware/ECU/docs/Hayabusa ECU 2.gif

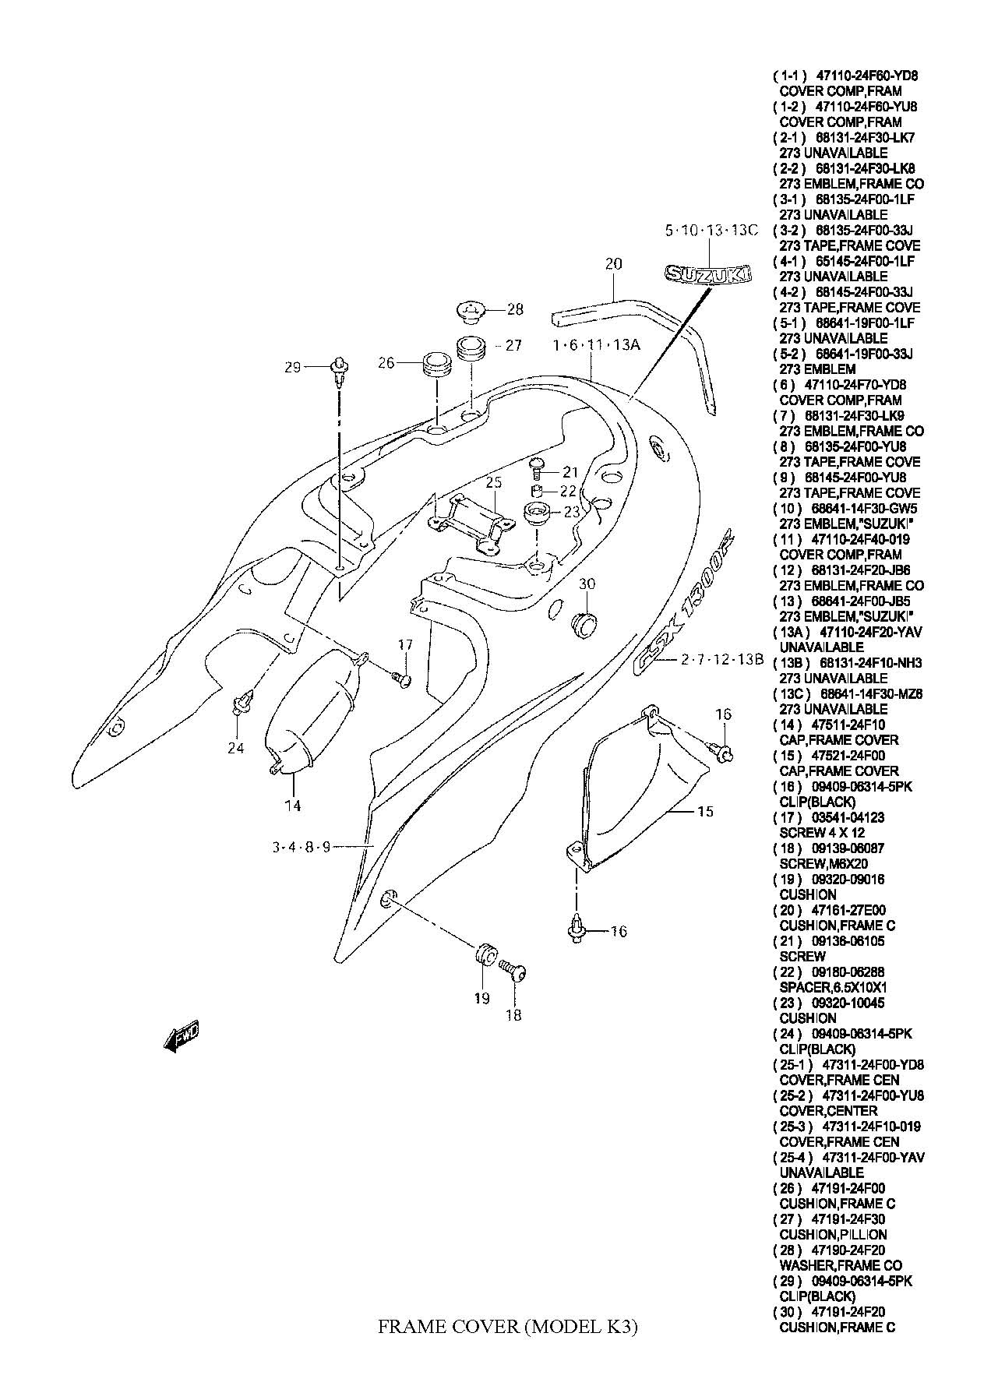
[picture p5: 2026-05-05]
docs/explosionszeichnung/other/FRAME_COVER_(MODEL_K3).jpg

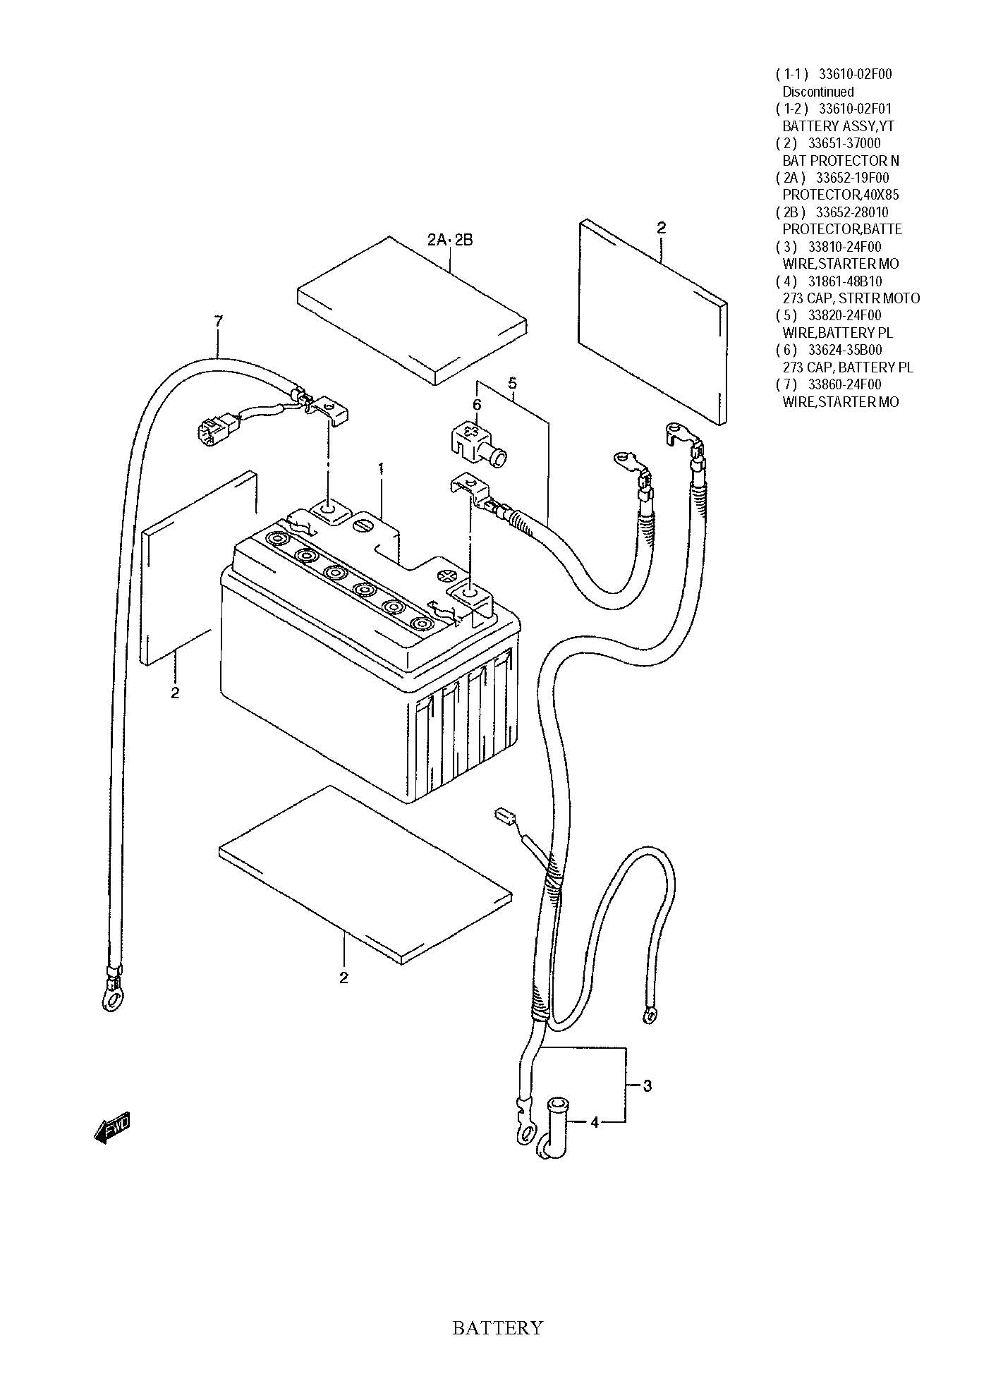
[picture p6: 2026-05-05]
docs/explosionszeichnung/BATTERY.jpg

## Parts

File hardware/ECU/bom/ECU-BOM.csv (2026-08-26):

Reference | Qty | Value | Footprint | MPN | Manufacturer | DigiKey | DK_Stock | Mouser | MO_Stock | Chosen_Distributor | Datasheet | Validated | DNP | Notes
BT1 | 1 | ML2032 | BatteryHolder_Keystone_3034_1x20mm | 3034 | Keystone Electronics | 36-3034-ND |  |  |  | DigiKey | https://www.digikey.de/de/products/result?keywords=36-3034-ND |  |  | SMD-Halter 20 mm (Keystone 3034); Zelle ML2032 separat: Jauch ML2032 / DK 1908-ML2032-ND. Keine CR2032 (nicht ladbar)!
C1,C38,C41,C43,C35,C42,C36,C37,C68,C74,C67,C21,C25,C22,C31,C32,C30,C34,C23,C24,C77,C7 | 22 | 100nF | 0805 | CC0805KRX7R9BB104 | Yageo | 311-1140-1-ND |  |  |  | DigiKey | https://www.digikey.de/de/products/result?keywords=311-1140-1-ND
C4 | 1 | 4.7nF | 0805 | CC0805KRX7R9BB472 | Yageo | 311-1133-1-ND |  |  |  | DigiKey | https://www.digikey.de/de/products/result?keywords=311-1133-1-ND
C5 | 1 | 10uF | 1206 | GRM31CR71E106KA12L | Murata | 490-6518-1-ND |  |  |  | DigiKey | https://www.digikey.de/de/products/result?keywords=490-6518-1-ND
C6 | 1 | 100nF 100V | 1206 | C1206C104K1RACTU | KEMET | 399-C1206C104K1RACTUCT-ND |  |  |  | DigiKey | https://www.digikey.de/de/products/result?keywords=399-C1206C104K1RACTUCT-ND
C8,C9 | 2 | 470pF | 0805 | CC0805KRX7R9BB471 | Yageo | 311-1124-1-ND |  |  |  | DigiKey | https://www.digikey.de/de/products/result?keywords=311-1124-1-ND
C11,C75 | 2 | 0.01uF | 0805 | CC0805KRX7R9BB103 | Yageo | 311-1136-1-ND |  |  |  | DigiKey | https://www.digikey.de/de/products/result?keywords=311-1136-1-ND
C12,C10,C26 | 3 | 1nF | 0805 | C0805C102J5HACAUTO | Kemet | 399-16591-1-ND |  |  |  | DigiKey | https://www.digikey.de/de/products/result?keywords=399-16591-1-ND
C13,C3,C2,C15,C17 | 5 | 0.1uF | 0805 | CC0805KRX7R9BB104 | Yageo | 311-1140-1-ND |  |  |  | DigiKey | https://www.digikey.de/de/products/result?keywords=311-1140-1-ND
C14 | 1 | 1uF | 0805 | CC0805KKX7R7BB105 | Yageo | 311-1365-1-ND |  |  |  | DigiKey | https://www.digikey.de/de/products/result?keywords=311-1365-1-ND
C18,C16 | 2 | 33uF | CP_Elec_6.3x7.7 | EEE-1HA330XP | Panasonic | PCE3925CT-ND |  |  |  | DigiKey | https://www.digikey.de/de/products/result?keywords=PCE3925CT-ND
C20,C19,C51,C52 | 4 | 100n | 0805 | CC0805KRX7R9BB104 | Yageo | 311-1140-1-ND |  |  |  | DigiKey | https://www.digikey.de/de/products/result?keywords=311-1140-1-ND
C40,C39,C28,C29,C27,C33 | 6 | 10nF | 0805 | CC0805KRX7R9BB103 | Yageo | 311-1136-1-ND |  |  |  | DigiKey | https://www.digikey.de/de/products/result?keywords=311-1136-1-ND
C45,C44 | 2 | 10n | 0805 | CC0805KRX7R9BB103 | Yageo | 311-1136-1-ND |  |  |  | DigiKey | https://www.digikey.de/de/products/result?keywords=311-1136-1-ND
C46 | 1 | 100u/50V | CP_Elec_8x10 | EEE-FK1H101GP | Panasonic | PCE4323CT-ND |  |  |  | DigiKey | https://www.digikey.de/de/products/result?keywords=PCE4323CT-ND
C47 | 1 | 1u | 0805 | CC0805KKX7R7BB105 | Yageo | 311-1365-1-ND |  |  |  | DigiKey | https://www.digikey.de/de/products/result?keywords=311-1365-1-ND
C48 | 1 | 220n | 0805 | CC0805KKX7R9BB224 | Yageo | 311-1887-1-ND |  |  |  | DigiKey | https://www.digikey.de/de/products/result?keywords=311-1887-1-ND
C49 | 1 | 22n | 0805 | CC0805KRX7R9BB223 | Yageo | 311-1138-1-ND |  |  |  | DigiKey | https://www.digikey.de/de/products/result?keywords=311-1138-1-ND
C50 | 1 | 1n | 0805 | C0805C102J5HACAUTO | KEMET | 399-16591-1-ND |  |  |  | DigiKey | https://www.digikey.de/de/products/result?keywords=399-16591-1-ND
C53,C73,C54,C65 | 4 | 100nF/100V | 1210 | C1210C104K1RACTU | KEMET | 399-C1210C104K1RACTUCT-ND |  |  |  | DigiKey | https://www.digikey.de/de/products/result?keywords=399-C1210C104K1RACTUCT-ND
C56,C55 | 2 | 4.7uF/100V | 1210 | C3225X7S2A475K200AB | TDK | 445-6042-1-ND |  |  |  | DigiKey | https://www.digikey.de/de/products/result?keywords=445-6042-1-ND
C57 | 1 | 1uF/50V | 0805 | CC0805KKX7R9BB105 | Yageo | 311-1886-1-ND |  |  |  | DigiKey | https://www.digikey.de/de/products/result?keywords=311-1886-1-ND
C58,C63 | 2 | 10uF/10V | 0805 | CL21A106KPFNNNE | Samsung Electro-Mechanics | 1276-1052-1-ND |  |  |  | DigiKey | https://www.digikey.de/de/products/result?keywords=1276-1052-1-ND
C60 | 1 | 39pF | 0805 | CC0805JRNPO9BN390 | Yageo | 311-1106-1-ND |  |  |  | DigiKey | https://www.digikey.de/de/products/result?keywords=311-1106-1-ND
C61,C69 | 2 | 100uF/50V | CP_Elec_8x10 | EEE-FK1H101GP | Panasonic | PCE4323CT-ND |  |  |  | DigiKey | https://www.digikey.de/de/products/result?keywords=PCE4323CT-ND
C62 | 1 | 6800pF | 0805 | CC0805KRX7R9BB682 | Yageo | 311-1135-1-ND |  |  |  | DigiKey | https://www.digikey.de/de/products/result?keywords=311-1135-1-ND
C64 | 1 | 22uF/10V | 1210 | GRM32ER71A226KE20L | Murata | 490-1876-1-ND |  |  |  | DigiKey | https://www.digikey.de/de/products/result?keywords=490-1876-1-ND
C66,C59 | 2 | 100nF/25V | 0805 | CC0805KRX7R9BB104 | Yageo | 311-1140-1-ND |  |  |  | DigiKey | https://www.digikey.de/de/products/result?keywords=311-1140-1-ND
C71 | 1 | 10uF/50V X7R | 1210 | C3225X7R1H106K250AC | TDK | 445-C3225X7R1H106K250ACCT-ND |  |  |  | DigiKey | https://www.digikey.de/de/products/result?keywords=445-C3225X7R1H106K250ACCT-ND
C72,C70 | 2 | 47uF/10V X7R | 1210 | CL32A476KOJNNNE | Samsung Electro-Mechanics | 1276-3376-1-ND |  |  |  | DigiKey | https://www.digikey.de/de/products/result?keywords=1276-3376-1-ND
C78,C80,C76 | 3 | CC0805KRX7R9BB104 | 0805 | CC0805KRX7R9BB104 | Yageo | 311-1140-1-ND |  | 603-CC805KRX7R9BB104 |  | DigiKey | https://www.yageo.com/upload/media/product/productsearch/datasheet/mlcc/UPY-GPHC_X7R_6.3V-to-50V_20.pdf
C79 | 1 | CC0805KKX7R7BB475 | 0805 | CC0805KKX7R7BB475 | Yageo | 311-1883-1-ND |  | 603-CC805KKX7R7BB475 |  | DigiKey | https://www.digikey.de/de/products/result?keywords=311-1883-1-ND
C82,C81 | 2 | CC0805JRX7R9BB332 | 0805 | CC0805JRX7R9BB332 | Yageo | 311-4277-1-ND |  |  |  | DigiKey | https://yageogroup.com/content/datasheet/asset/file/UPY-GPHC_X7R_6_3V-TO-250V
D1 | 1 | D_Schottky | PowerDI-123 | DFLS240-7 | Diodes Incorporated | DFLS240-7DICT-ND |  |  |  | DigiKey | https://www.digikey.de/de/products/result?keywords=DFLS240-7DICT-ND
D2 | 1 | SMAJ5.0A | SMA | SMAJ5.0A | Littelfuse | SMAJ5.0ALFCT-ND |  |  |  | DigiKey | https://www.digikey.de/de/products/result?keywords=SMAJ5.0ALFCT-ND
D3 | 1 | NUP2105L | SOT-23 | NUP2105LT1G | onsemi | NUP2105LT1GOSCT-ND |  |  |  | DigiKey | https://www.digikey.de/de/products/result?keywords=NUP2105LT1GOSCT-ND
D11,D12,D10,D13 | 4 | D | SOD-323 | 1N4448WX-TP | MCC | 1N4448WXTPMSCT-ND |  |  |  | DigiKey | https://www.digikey.de/de/products/result?keywords=1N4448WXTPMSCT-ND
D15,D8,D14,D9 | 4 | LED | 0805 | LTST-C170KRKT | Lite-On | 160-1415-1-ND |  |  |  | DigiKey | https://www.digikey.de/de/products/result?keywords=160-1415-1-ND
D22 | 1 | 3V6 1W (SMA) | SMA | 1SMA5914BT3G | onsemi | 1SMA5914BT3GOSCT-ND |  |  |  | DigiKey | https://www.digikey.de/de/products/result?keywords=1SMA5914BT3GOSCT-ND
D30,D27,D26,D28,D29,D7,D4,D5,D6,D20,D19,D25,D24,D23,D17,D16,D18,D21,D46,D47 | 20 | BAV199 | SOT-23 | BAV199LT1G | onsemi | BAV199LT1GOSCT-ND |  |  |  | DigiKey | https://www.digikey.de/de/products/result?keywords=BAV199LT1GOSCT-ND
D31,D35,D40,D34,D36,D32,D33,D39 | 8 | SS34 | SMA | B340A-13-F | Diodes Incorporated | B340A-FDICT-ND |  |  |  | DigiKey | https://www.digikey.de/de/products/result?keywords=B340A-FDICT-ND |  |  | Ersatz fuer SS34: 3A/40V Schottky in SMA (SS34 meist SMC)
D38,D37 | 2 | 1N4148W | SOD-123 | 1N4148W-7-F | Diodes Incorporated | 1N4148W-FDICT-ND |  |  |  | DigiKey | https://www.digikey.de/de/products/result?keywords=1N4148W-FDICT-ND
D41 | 1 | SM8S24A | DO-218AB | SM8S24A | SMC Diode Solutions | 1655-SM8S24ACT-ND |  |  |  | DigiKey | https://www.digikey.de/de/products/result?keywords=1655-SM8S24ACT-ND
D42 | 1 | B560C | SMC | B560C-13-F | Diodes Incorporated | B560C-FDICT-ND |  |  |  | DigiKey | https://www.digikey.de/de/products/result?keywords=B560C-FDICT-ND
D43,D44,D45 | 3 | LED grn | 0805 | LTST-C170GKT | Lite-On | 160-1179-1-ND |  |  |  | DigiKey | https://www.digikey.de/de/products/result?keywords=160-1179-1-ND
F1 | 1 | 150mA | 1812 | 1812L014DR | Littelfuse | F3353CT-ND |  |  |  | DigiKey | https://www.digikey.de/de/products/result?keywords=F3353CT-ND |  |  | PTC 140mA hold (naechster Standardwert zu 150mA), 60V
F2 | 1 | 3A / 63V | 1206 | 0483003.DR | Littelfuse | 18-0483003.DRCT-ND |  |  |  | DigiKey | https://www.digikey.de/de/products/result?keywords=18-0483003.DRCT-ND |  |  | 3A/65V flink 1206 (63V-Anforderung: 437er-Serie schafft nur 35V)
IC1 | 1 | MAX9926UAEE_V+ | QSOP-16_3.9x4.9mm_P0.635mm | MAX9926UAEE/V+ | Analog Devices | MAX9926UAEE/V+-ND |  | 700-MAX9926UAEE/V+ |  | DigiKey | https://componentsearchengine.com/Datasheets/1/MAX9926UAEE_V+.pdf
IC3,IC4,IC2 | 3 | ZXMS6006DT8 | SOT153P700X170-8N | ZXMS6006DT8TA | Diodes Incorporated | ZXMS6006DT8TADICT-ND |  |  |  | DigiKey | https://www.digikey.de/de/products/result?keywords=ZXMS6006DT8TADICT-ND |  |  | Last Time Buy 06.01.2027 - Bedarf sichern
IC5 | 1 | LD1117S33 | SOT-223-3_TabPin2 | LD1117S33CTR | STMicroelectronics | 497-1241-1-ND |  |  |  | DigiKey | https://www.digikey.de/de/products/result?keywords=497-1241-1-ND
IC6 | 1 | 74AHCT125T14-13 | TSSOP-14_4.4x5mm_P0.65mm | 74AHCT125T14-13 | Diodes Incorporated | 31-74AHCT125T14-13CT-ND |  | 621-74AHCT125T14-13 |  | DigiKey | https://www.diodes.com/assets/Datasheets/74AHCT125.pdf
IC7 | 1 | TPIC8101DW | SOIC-20W_7.5x12.8mm_P1.27mm | TPIC8101DWR | Texas Instruments | 296-15132-1-ND |  | 595-TPIC8101DW |  | DigiKey | http://www.ti.com/general/docs/lit/getliterature.tsp?genericPartNumber=TPIC8101&&fileType=pdf
J1 | 1 | Conn_01x04 | PinHeader_1x04_P2.54mm_Vertical | 61300411121 | Würth Elektronik | 732-5317-ND |  |  |  | DigiKey | https://www.digikey.de/de/products/result?keywords=732-5317-ND
J2 | 1 |  | 6437288-3 | 6437288-3 | TE Connectivity | A122211-ND |  |  |  | DigiKey | https://www.digikey.de/de/products/result?keywords=A122211-ND |  |  | Gegenstueck/Kontakte separat beschaffen (SUPERSEAL 1.0 60-pol)
L1 | 1 | 10uH / 3.3A | Bourns_SRR1260 | SRR1260-100M | Bourns | SRR1260-100MCT-ND |  |  |  | DigiKey | https://www.digikey.de/de/products/result?keywords=SRR1260-100MCT-ND
L2 | 1 | 8.2uH / 5A | Bourns_SRR1260 | SRR1260A-8R2Y | Bourns | SRR1260A-8R2YCT-ND |  |  |  | DigiKey | https://www.digikey.de/de/products/result?keywords=SRR1260A-8R2YCT-ND |  |  | AEC-Q200-A-Serie, Irms 5.7A
Q4,Q1,Q3,Q2 | 4 | ISL9V5036P3-F085 | TO254P470X1016X2019-3P | ISL9V5036P3-F085 | onsemi | ISL9V5036P3-F085-ND |  | 512-ISL9V5036P3-F085 |  | DigiKey | https://www.onsemi.com/pub/Collateral/ISL9V5036S3ST-D.PDF
Q5 | 1 | BSS138 | SOT-23 | BSS138 | onsemi | BSS138CT-ND |  |  |  | DigiKey | https://www.digikey.de/de/products/result?keywords=BSS138CT-ND
Q6 | 1 | SQM120N06-3M5L | TO-263-2 | SQM120N06-3M5L_GE3 | Vishay Siliconix | SQM120N06-3M5L_GE3CT-ND |  |  |  | DigiKey | https://www.digikey.de/de/products/result?keywords=SQM120N06-3M5L_GE3CT-ND |  |  | Ersatz: SQJ973EP existiert nicht; N-Kanal 60V 3.5mOhm fuer LM74700-Ideal-Diode
R1,R92,R122,R18,R17,R63,R75,R124,R51,R40,R52,R41,R95,R93,R96,R94,R97,R98 | 18 | 1k | 0805 | RC0805FR-071KL | Yageo | 311-1.00KCRCT-ND |  |  |  | DigiKey | https://www.digikey.de/de/products/result?keywords=311-1.00KCRCT-ND
R7,R6 | 2 | 60.4R | 0805 | RC0805FR-0760R4L | Yageo | 311-60.4CRCT-ND |  |  |  | DigiKey | https://www.digikey.de/de/products/result?keywords=311-60.4CRCT-ND
R10,R21,R9,R22 | 4 | 0R DNP | 0805 | RC0805JR-070RL | Yageo | 311-0.0ARCT-ND |  |  |  | DigiKey | https://www.digikey.de/de/products/result?keywords=311-0.0ARCT-ND |  | yes
R13,R20,R19,R11 | 4 | 0R | 0805 | RC0805JR-070RL | Yageo | 311-0.0ARCT-ND |  |  |  | DigiKey | https://www.digikey.de/de/products/result?keywords=311-0.0ARCT-ND
R16,R15 | 2 | 10k DNP | 0805 | RC0805FR-0710KL | Yageo | 311-10.0KCRCT-ND |  |  |  | DigiKey | https://www.digikey.de/de/products/result?keywords=311-10.0KCRCT-ND |  | yes
R23,R24,R25,R26 | 4 | 10k | 1206 | RC1206FR-7W10KL | Yageo | 13-RC1206FR-7W10KLTR-ND |  |  |  | DigiKey | https://www.digikey.de/de/products/result?keywords=13-RC1206FR-7W10KLTR-ND
R29,R53,R28,R54 | 4 | 33 | 0805 | RC0805FR-7W33RL | Yageo | 13-RC0805FR-7W33RLCT-ND |  |  |  | DigiKey | https://www.digikey.de/de/products/result?keywords=13-RC0805FR-7W33RLCT-ND
R30 | 1 | 20m | 2512 | WSL2512R0200FEA | Vishay Dale | WSLG-.02CT-ND |  |  |  | DigiKey | https://www.digikey.de/de/products/result?keywords=WSLG-.02CT-ND
R42,R45,R38,R36,R44,R39,R43,R37 | 8 | 18k | 1206 | RC1206FR-0718KL | Yageo | 311-18.0KFRCT-ND |  |  |  | DigiKey | https://www.digikey.de/de/products/result?keywords=311-18.0KFRCT-ND
R46,R49,R48,R47 | 4 | 4.02k | 0805 | RC0805FR-074K02L | Yageo | 311-4.02KCRCT-ND |  |  |  | DigiKey | https://www.digikey.de/de/products/result?keywords=311-4.02KCRCT-ND
R50,R104,R99,R100,R103,R101,R112,R108,R109,R102 | 10 | 100k | 0805 | RC0805FR-07100KL | Yageo | 311-100KCRCT-ND |  |  |  | DigiKey | https://www.digikey.de/de/products/result?keywords=311-100KCRCT-ND
R56,R55 | 2 | 2k49 | 0805 | RC0805FR-072K49L | Yageo | 311-2.49KCRCT-ND |  |  |  | DigiKey | https://www.digikey.de/de/products/result?keywords=311-2.49KCRCT-ND
R72 | 1 | 47k | 0805 | RC0805FR-0747KL | Yageo | 311-47.0KCRCT-ND |  |  |  | DigiKey | https://www.digikey.de/de/products/result?keywords=311-47.0KCRCT-ND
R83,R87,R88,R82,R66,R64,R65 | 7 | 12k | 0805 | RC0805FR-0712KL | Yageo | 311-12.0KCRCT-ND |  |  |  | DigiKey | https://www.digikey.de/de/products/result?keywords=311-12.0KCRCT-ND
R84,R85,R67,R69,R68 | 5 | 20k | 0805 | RC0805FR-0720KL | Yageo | 311-20.0KCRCT-ND |  |  |  | DigiKey | https://www.digikey.de/de/products/result?keywords=311-20.0KCRCT-ND
R86,R77,R76,R120,R12,R14,R61,R60,R62,R58,R59,R70 | 12 | 470R | 0805 | RC0805FR-07470RL | Yageo | 311-470CRCT-ND |  |  |  | DigiKey | https://www.digikey.de/de/products/result?keywords=311-470CRCT-ND
R89,R80,R79,R78,R81,R71,R74,R73,R8,R5,R4,R3,R2,R123,R35,R34,R31,R32,R33,R27,R106,R110,R113,R111 | 24 | 10k | 0805 | RC0805FR-0710KL | Yageo | 311-10.0KCRCT-ND |  |  |  | DigiKey | https://www.digikey.de/de/products/result?keywords=311-10.0KCRCT-ND
R90 | 1 | 5k6 | 0805 | RC0805FR-075K6L | Yageo | 311-5.60KCRCT-ND |  |  |  | DigiKey | https://www.digikey.de/de/products/result?keywords=311-5.60KCRCT-ND
R91 | 1 | 1M | 0805 | RC0805FR-071ML | Yageo | 311-1.00MCRCT-ND |  |  |  | DigiKey | https://www.digikey.de/de/products/result?keywords=311-1.00MCRCT-ND
R105 | 1 | 15k | 0805 | RC0805FR-0715KL | Yageo | 311-15.0KCRCT-ND |  |  |  | DigiKey | https://www.digikey.de/de/products/result?keywords=311-15.0KCRCT-ND
R107 | 1 | 330k | 0805 | RC0805FR-07330KL | Yageo | 311-330KCRCT-ND |  |  |  | DigiKey | https://www.digikey.de/de/products/result?keywords=311-330KCRCT-ND
R114 | 1 | 237k | 0805 | RC0805FR-07237KL | Yageo | 311-237KCRCT-ND |  |  |  | DigiKey | https://www.digikey.de/de/products/result?keywords=311-237KCRCT-ND
R115 | 1 | 56k2 | 0805 | RC0805FR-0756K2L | Yageo | 311-56.2KCRCT-ND |  |  |  | DigiKey | https://www.digikey.de/de/products/result?keywords=311-56.2KCRCT-ND
R116 | 1 | 162k | 0805 | RC0805FR-07162KL | Yageo | 311-162KCRCT-ND |  |  |  | DigiKey | https://www.digikey.de/de/products/result?keywords=311-162KCRCT-ND
R117 | 1 | 53k6 | 0805 | RC0805FR-0753K6L | Yageo | 311-53.6KCRCT-ND |  |  |  | DigiKey | https://www.digikey.de/de/products/result?keywords=311-53.6KCRCT-ND
R118 | 1 | 10k2 | 0805 | RC0805FR-0710K2L | Yageo | 311-10.2KCRCT-ND |  |  |  | DigiKey | https://www.digikey.de/de/products/result?keywords=311-10.2KCRCT-ND
R119 | 1 | 13k | 0805 | RC0805FR-0713KL | Yageo | 311-13.0KCRCT-ND |  |  |  | DigiKey | https://www.digikey.de/de/products/result?keywords=311-13.0KCRCT-ND
R121,R57 | 2 | 2k2 | 0805 | RC0805FR-072K2L | Yageo | 311-2.20KCRCT-ND |  |  |  | DigiKey | https://www.digikey.de/de/products/result?keywords=311-2.20KCRCT-ND
R125 | 1 | 2k | 0805 | RC0805FR-072KL | Yageo | 311-2.00KCRCT-ND |  | 603-RC0805FR-072KL |  | DigiKey | http://www.yageo.com/documents/recent/PYu-RC_Group_51_RoHS_L_10.pdf
R129,R130,R128,R127 | 4 | RC0805FR-07100KL | 0805 | RC0805FR-07100KL | Yageo | 311-100KCRCT-ND |  | 603-RC0805FR-07100KL |  | DigiKey | http://www.yageo.com/documents/recent/PYu-RC_Group_51_RoHS_L_10.pdf
R131,R132,R126 | 3 | RC0805FR-071ML | 0805 | RC0805FR-071ML | Yageo | 311-1.00MCRCT-ND |  | 603-RC0805FR-071ML |  | DigiKey | https://www.yageo.com/upload/media/product/productsearch/datasheet/rchip/PYu-RC_Group_51_RoHS_L_11.pdf
U1 | 1 | Teensy4.1 | Teensy41 | DEV-16771 | SparkFun (PJRC) | 1568-16771-ND |  |  |  | DigiKey | https://www.digikey.de/de/products/result?keywords=1568-16771-ND
U2 | 1 | W25Q32JVSS | SOIC-8_5.3x5.3mm_P1.27mm | W25Q32RVCSJQ TR | Winbond | 256-W25Q32RVCSJQTR-ND |  |  |  | DigiKey | http://www.winbond.com/resource-files/w25q32jv%20revg%2003272018%20plus.pdf |  |  | Nur ~39 St. bei DigiKey; Alternative W25Q32JVSSIQ via Mouser
U3 | 1 | MCP2562-E-SN | SOIC-8_3.9x4.9mm_P1.27mm | MCP2562-E/SN | Microchip Technology | MCP2562-E/SN-ND |  |  |  | DigiKey | http://ww1.microchip.com/downloads/en/DeviceDoc/25167A.pdf
U4 | 1 | 74AHC1G32 | SOT-353_SC-70-5 | SN74AHC1G32DCKR | Texas Instruments | 296-8749-1-ND |  |  |  | DigiKey | http://www.ti.com/lit/sg/scyt129e/scyt129e.pdf
U5 | 1 | ADXL343 | LGA-14_3x5mm_P0.8mm_LayoutBorder1x6y | ADXL343BCCZ-RL | Analog Devices | ADXL343BCCZ-RLCT-ND |  |  |  | DigiKey | https://www.analog.com/media/en/technical-documentation/data-sheets/ADXL343.pdf
U6 | 1 | USBLC6-2SC6 | SOT-23-6 | USBLC6-2SC6 | STMicroelectronics | 497-5235-1-ND |  |  |  | DigiKey | https://www.digikey.de/de/products/result?keywords=497-5235-1-ND
U7 | 1 | MC33810 | SOIC32-P0.65-33N | MCZ33810EK | NXP | MCZ33810EK-ND |  |  |  | DigiKey | https://www.digikey.de/de/products/result?keywords=MCZ33810EK-ND |  |  | Last Time Buy 30.04.2027 - Bedarf sichern
U8 | 1 | TPS3823-33DBV | SOT-23-5 | TPS3823-33DBVR | Texas Instruments | 296-1357-1-ND |  |  |  | DigiKey | https://www.digikey.de/de/products/result?keywords=296-1357-1-ND
U9 | 1 | 74LVC1G00 | SOT-353_SC-70-5 | SN74LVC1G00DCKR | Texas Instruments | 296-9846-1-ND |  |  |  | DigiKey | https://www.digikey.de/de/products/result?keywords=296-9846-1-ND
U11,U10 | 2 | LMV324 | SOIC-14_3.9x8.7mm_P1.27mm | LMV324IDR | Texas Instruments | 296-9569-1-ND |  |  |  | DigiKey | https://www.digikey.de/de/products/result?keywords=296-9569-1-ND
U12 | 1 | DRV8434A | HTSSOP-28-1EP_4.4x9.7mm_P0.65mm_EP2.85x5.4mm_ThermalVias | DRV8434APWPR | Texas Instruments | 296-DRV8434APWPRCT-ND |  |  |  | DigiKey | https://www.digikey.de/de/products/result?keywords=296-DRV8434APWPRCT-ND
U13,U14 | 2 | BTF3050TE | TO-252-5_TabPin3 | BTF3050TEATMA1 | Infineon | BTF3050TEATMA1CT-ND |  |  |  | DigiKey | https://www.digikey.de/de/products/result?keywords=BTF3050TEATMA1CT-ND
U15 | 1 | LM74700-Q1 | SOT-23-6 | LM74700QDBVRQ1 | Texas Instruments | 296-LM74700QDBVRQ1CT-ND |  |  |  | DigiKey | https://www.digikey.de/de/products/result?keywords=296-LM74700QDBVRQ1CT-ND
U16 | 1 | TPS54360B-Q1 | HSOP-8-1EP_3.9x4.9mm_P1.27mm_EP2.41x3.1mm_ThermalVias | TPS54360BQDDARQ1 | Texas Instruments | 296-46985-1-ND |  |  |  | DigiKey | https://www.digikey.de/de/products/result?keywords=296-46985-1-ND
U17 | 1 | TPS7B6950-Q1 | SOT-223-3_TabPin2 | TPS7B6950QDCYRQ1 | Texas Instruments | 296-40985-1-ND |  |  |  | DigiKey | https://www.digikey.de/de/products/result?keywords=296-40985-1-ND
U18 | 1 | 74LVC1G125 | SOT-353_SC-70-5 | SN74LVC1G125DCKR | Texas Instruments | 296-11604-1-ND |  |  |  | DigiKey | https://www.digikey.de/de/products/result?keywords=296-11604-1-ND
Y1 | 1 | CSTCR4M00G53-R0 | Resonator_SMD_Murata_CSTCR_4.5x2x1.15mm | CSTCR4M00G53-R0 | Murata | 490-1200-1-ND |  |  |  | DigiKey | https://www.digikey.de/de/products/result?keywords=490-1200-1-ND

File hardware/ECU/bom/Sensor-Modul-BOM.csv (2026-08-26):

Reference | Qty | Value | Footprint | MPN | Manufacturer | DigiKey | DK_Stock | Mouser | MO_Stock | Chosen_Distributor | Datasheet | Validated | DNP | Notes
C7,C5,C3,C14,C17,C18,C15,C16,C13,C4,C6,C8 | 12 | 10nF | 0805 | CC0805KRX7R9BB103 | Yageo | 311-1136-1-ND |  |  |  | DigiKey | https://www.digikey.de/de/products/result?keywords=311-1136-1-ND
C11,C12,C1,C2 | 4 | 0.01uF | 0805 | CC0805KRX7R9BB103 | Yageo | 311-1136-1-ND |  |  |  | DigiKey | https://www.digikey.de/de/products/result?keywords=311-1136-1-ND
C23 | 1 | 100uF | 1206 | CL31A107MQHNNNE | Samsung Electro-Mechanics | 1276-1782-1-ND |  |  |  | DigiKey | https://www.digikey.de/de/products/result?keywords=1276-1782-1-ND
C33 | 1 | 4.7uF | 0805 | CC0805KKX7R7BB475 | Yageo | 311-1883-1-ND |  |  |  | DigiKey | https://www.digikey.de/de/products/result?keywords=311-1883-1-ND
C39,C24,C27,C28 | 4 | 1uF | 0805 | CC0805KKX7R7BB105 | Yageo | 311-1365-1-ND |  |  |  | DigiKey | https://www.digikey.de/de/products/result?keywords=311-1365-1-ND
C43,C45 | 2 | 2.2uF/50V | 1210 | C3225X7R1H225K250AB | TDK | 445-1431-1-ND |  |  |  | DigiKey | https://www.digikey.de/de/products/result?keywords=445-1431-1-ND
C44 | 1 | 4.7nF | 0805 | CC0805KRX7R9BB472 | Yageo | 311-1133-1-ND |  |  |  | DigiKey | https://www.digikey.de/de/products/result?keywords=311-1133-1-ND
C46 | 1 | 100nF/100V | 0805 | C0805C104K1RACTU | KEMET | 399-C0805C104K1RACTUCT-ND |  |  |  | DigiKey | https://www.digikey.de/de/products/result?keywords=399-C0805C104K1RACTUCT-ND
C47,C36,C37,C38,C50,C53,C41,C40,C34,C42,C26,C29 | 12 | 0.1uF | 0805 | CC0805KRX7R9BB104 | Yageo | 311-1140-1-ND |  |  |  | DigiKey | https://www.digikey.de/de/products/result?keywords=311-1140-1-ND
C48,C49 | 2 | 33uF | CP_Elec_6.3x7.7 | EEE-1HA330XP | Panasonic | PCE3925CT-ND |  |  |  | DigiKey | https://www.digikey.de/de/products/result?keywords=PCE3925CT-ND
C51,C52 | 2 | 22 µF | EEE1AA221P | EEE-FK1H220P | Panasonic | PCE3811CT-ND |  |  |  | DigiKey | http://industrial.panasonic.com/cdbs/www-data/pdf/RDE0000/ABA0000C1142.pdf |  |  | Ersatz: EEE-1HA220AP war 8mm-Durchmesser (Footprint 6.3mm) + NRND
C54 | 1 | 22uF/10V | 1210 | GRM32ER71A226KE20L | Murata | 490-1876-1-ND |  |  |  | DigiKey | https://www.digikey.de/de/products/result?keywords=490-1876-1-ND
C55,C35,C21,C22,C25,C9,C10,C19,C20,C32,C31,C30 | 12 | 100nF | 0805 | CC0805KRX7R9BB104 | Yageo | 311-1140-1-ND |  |  |  | DigiKey | https://www.digikey.de/de/products/result?keywords=311-1140-1-ND
D1,D7,D5,D6 | 4 | SMAJ5.0A | SMA | SMAJ5.0A | Littelfuse | SMAJ5.0ALFCT-ND |  |  |  | DigiKey | https://www.digikey.de/de/products/result?keywords=SMAJ5.0ALFCT-ND |  |  | 3.3V-SMA-TVS nicht lieferbar (MCC 16 Wo.); 5V-Standoff klemmt vergleichbar
D2 | 1 | SK510L | SMC | SK510L-TP | MCC | SK510L-TPMSCT-ND |  |  |  | DigiKey | https://www.digikey.de/de/products/result?keywords=SK510L-TPMSCT-ND |  |  | Ersatz fuer SS5P10 (TO-277-Package passte nicht zu SMC-Footprint)
D3 | 1 | SMBJ33A | SMB | SMBJ33A | Littelfuse | SMBJ33ALFCT-ND |  |  |  | DigiKey | https://www.digikey.de/de/products/result?keywords=SMBJ33ALFCT-ND
D4 | 1 | NUP2105L | SOT-23 | NUP2105LT1G | onsemi | NUP2105LT1GOSCT-ND |  |  |  | DigiKey | https://www.digikey.de/de/products/result?keywords=NUP2105LT1GOSCT-ND
D8 | 1 | SMCJ18A | SMC | SMCJ18A | Littelfuse | SMCJ18ALFCT-ND |  |  |  | DigiKey | https://www.digikey.de/de/products/result?keywords=SMCJ18ALFCT-ND
D9 | 1 | SL310A | SMA_Handsoldering | SL310A-TP | MCC | SL310A-TPMSCT-ND |  |  |  | DigiKey | https://www.digikey.de/de/products/result?keywords=SL310A-TPMSCT-ND
F3,F2,F1 | 3 | 50mA | 1206 | 0ZCJ0005FF2E | Bel Fuse | 5923-0ZCJ0005FF2ECT-ND |  |  |  | DigiKey | https://www.digikey.de/de/products/result?keywords=5923-0ZCJ0005FF2ECT-ND
F4 | 1 | 0.5A/30V | 1812 | 1812L050/60MR | Littelfuse | F8132CT-ND |  |  |  | DigiKey | https://www.digikey.de/de/products/result?keywords=F8132CT-ND
IC1,IC4,IC2,IC3 | 4 | MAX31855KASA+ | SOIC127P600X175-8N | MAX31855KASA+T | Analog Devices | MAX31855KASA+TCT-ND |  | 700-MAX31855KASA+ |  | DigiKey | https://datasheets.maximintegrated.com/en/ds/MAX31855.pdf
IC5 | 1 | STM32G474RBT6 | QFP50P1200X1200X160-64N | STM32G474RBT6 | STMicroelectronics | STM32G474RBT6-ND |  | 511-STM32G474RBT6 |  | DigiKey | https://www.st.com/resource/en/datasheet/stm32g474cb.pdf |  |  | Aktuell 0 Lager bei DigiKey - Beschaffung pruefen (Alternative STM32G474RET6 pinkompatibel)
IC6 | 1 | LD1117S33C | LD1117S33C | LD1117S33CTR | STMicroelectronics | 497-1241-1-ND |  | N/A |  | DigiKey | https://www.st.com/resource/en/datasheet/ld1117.pdf
J2,J1 | 2 | MX23A12NF1 | MX23A12NF1 | MX23A12NF1 | JAE Electronics | 670-1683-ND |  | 656-MX23A12NF1 |  | DigiKey | https://www.jae.com/direct/topics/topics_file_download/topics_id=64755&ext_no=06&_lang=en&v= |  |  | Gegenstecker MX23A12SF1 + Kontakte separat
J3 | 1 | 1-776266-1 | 17762661 | 1-776266-1 | TE Connectivity | A128219-ND |  | 571-1-776266-1 |  | DigiKey | https://componentsearchengine.com/Datasheets/1/1-776266-1.pdf |  |  | AMPSEAL 14-pol; Gegenstecker+Kontakte separat beschaffen
J4 | 1 | Conn_01x06_Pin | PinHeader_1x06_P2.54mm_Vertical | 61300611121 | Würth Elektronik | 732-5319-ND |  |  |  | DigiKey | https://www.digikey.de/de/products/result?keywords=732-5319-ND
L1 | 1 | BLM18AG601SN1 | 0603 | BLM18AG601SN1D | Murata | 490-1014-1-ND |  |  |  | DigiKey | https://www.digikey.de/de/products/result?keywords=490-1014-1-ND
L2 | 1 | 10uH/1A | 1210 | LQH32PN100MNCL | Murata | 490-LQH32PN100MNCLCT-ND |  |  |  | DigiKey | https://www.digikey.de/de/products/result?keywords=490-LQH32PN100MNCLCT-ND |  |  | Irms 900mA / Isat 1A
L3 | 1 | 10uH/1.8A | Bourns_SRN6045TA | SRN6045TA-100M | Bourns | SRN6045TA-100MCT-ND |  |  |  | DigiKey | https://www.digikey.de/de/products/result?keywords=SRN6045TA-100MCT-ND
Q1 | 1 | SQM120N06-3M5L | TO-263-2 | SQM120N06-3M5L_GE3 | Vishay Siliconix | SQM120N06-3M5L_GE3CT-ND |  | 942-IRLB8721PBF |  | DigiKey | http://uk.rs-online.com/web/p/products/7259322 |  |  | Ersatz: IPB80N06S4L-07 discontinued (Infineon PCN 2023)
R1,R4,R12,R14,R13,R11,R3,R2 | 8 | 100R | ERJ6ENF1000V | ERJ-6ENF1000V | Panasonic | P100CCT-ND |  |  |  | DigiKey | http://docs-europe.electrocomponents.com/webdocs/13ba/0900766b813ba21b.pdf
R24,R23,R30 | 3 | 2k | RESC2012X60N | RC0805FR-072KL | Yageo | 311-2.00KCRCT-ND |  | 603-RC0805FR-072KL |  | DigiKey | http://www.yageo.com/documents/recent/PYu-RC_Group_51_RoHS_L_10.pdf
R32,R38,R40 | 3 | 10k | 1206 | RC1206FR-7W10KL | Yageo | 13-RC1206FR-7W10KLTR-ND |  |  |  | DigiKey | https://www.digikey.de/de/products/result?keywords=13-RC1206FR-7W10KLTR-ND
R41 | 1 | 100 | ERJ6ENF1000V | ERJ-6ENF1000V | Panasonic | P100CCT-ND |  |  |  | DigiKey | http://docs-europe.electrocomponents.com/webdocs/13ba/0900766b813ba21b.pdf
R42,R50,R7,R20,R17,R19,R8,R10,R9,R18 | 10 | 10k | 0805 | RC0805FR-0710KL | Yageo | 311-10.0KCRCT-ND |  |  |  | DigiKey | https://www.digikey.de/de/products/result?keywords=311-10.0KCRCT-ND
R43 | 1 | 15k | 0805 | RC0805FR-0715KL | Yageo | 311-15.0KCRCT-ND |  |  |  | DigiKey | https://www.digikey.de/de/products/result?keywords=311-15.0KCRCT-ND
R44,R33,R37,R29,R22,R25,R36,R35,R26,R34,R31,R28,R21,R39,R27 | 15 | 1k | 0805 | RC0805FR-071KL | Yageo | 311-1.00KCRCT-ND |  |  |  | DigiKey | https://www.digikey.de/de/products/result?keywords=311-1.00KCRCT-ND
R45 | 1 | 10k | 0805 | RC0805JR-0710KL | Yageo | 311-10KARCT-ND |  |  |  | DigiKey | https://www.digikey.de/de/products/result?keywords=311-10KARCT-ND
R47,R46 | 2 | 60R4 | 0805 | RC0805FR-0760R4L | Yageo | 311-60.4CRCT-ND |  |  |  | DigiKey | https://www.digikey.de/de/products/result?keywords=311-60.4CRCT-ND
R48,R6,R15,R16,R5 | 5 | 0R | 0805 | RC0805JR-070RL | Yageo | 311-0.0ARCT-ND |  |  |  | DigiKey | https://www.digikey.de/de/products/result?keywords=311-0.0ARCT-ND
R49 | 1 | 40k2 | 0805 | RC0805FR-0740K2L | Yageo | 311-40.2KCRCT-ND |  |  |  | DigiKey | https://www.digikey.de/de/products/result?keywords=311-40.2KCRCT-ND
U1 | 1 | SP720 | SOIC-16_3.9x9.9mm_P1.27mm | SP720ABTG | Littelfuse | F3162CT-ND |  |  |  | DigiKey | https://m.littelfuse.com/~/media/electronics/datasheets/tvs_diode_arrays/littelfuse_tvs_diode_array_sp720_datasheet.pdf.pdf
U2 | 1 | CSTNE16M0V530000R0 | CSTNE16M0V530000R0 | CSTNE16M0V530000R0 | Murata | 490-17948-1-ND |  | 81-CSTNE16M0V530000R |  | DigiKey | https://www.murata.com/products/productdata/8801160822814/SPEC-CSTNE16M0V530000R0.pdf
U3 | 1 | MCP2562FD-E/SN | SOIC-8_3.9x4.9mm_P1.27mm | MCP2562FD-E/SN | Microchip Technology | MCP2562FD-E/SN-ND |  |  |  | DigiKey | http://ww1.microchip.com/downloads/en/DeviceDoc/25167A.pdf
U4 | 1 | TPS560430Y-Q1 | SOT-23-6 | TPS560430YQDBVRQ1 | Texas Instruments | 296-TPS560430YQDBVRQ1CT-ND |  |  |  | DigiKey | https://www.digikey.de/de/products/result?keywords=296-TPS560430YQDBVRQ1CT-ND |  |  | X-Q1-Variante existiert nicht; Y=2.1MHz passt zu 10uH-Spule

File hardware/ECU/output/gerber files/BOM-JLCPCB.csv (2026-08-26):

Bezeichnung | Bezeichner | Footprint
ML2032 | BT1 | BatteryHolder_Keystone_3034_1x20mm
100nF | C1, C7, C21, C22, C23, C24, C25, C30, C31, C32, C34, C35, C36, C37, C38, C41, C42, C43, C67, C68, C74, C77 | C_0805_2012Metric
0.1uF | C2, C3, C13, C15, C17 | C_0805_2012Metric
4.7nF | C4 | C_0805_2012Metric
10uF | C5 | C_1206_3216Metric
100nF 100V | C6 | C_1206_3216Metric
470pF | C8, C9 | C_0805_2012Metric
1nF | C10, C12, C26 | C_0805_2012Metric
0.01uF | C11, C75 | C_0805_2012Metric
1uF | C14 | C_0805_2012Metric
33uF | C16, C18 | CP_Elec_6.3x7.7
100n | C19, C20, C51, C52 | C_0805_2012Metric
10nF | C27, C28, C29, C33, C39, C40 | C_0805_2012Metric
10n | C44, C45 | C_0805_2012Metric
100u/50V | C46 | CP_Elec_8x10
1u | C47 | C_0805_2012Metric
220n | C48 | C_0805_2012Metric
22n | C49 | C_0805_2012Metric
1n | C50 | C_0805_2012Metric
100nF/100V | C53, C54, C65, C73 | C_1210_3225Metric
4.7uF/100V | C55, C56 | C_1210_3225Metric
1uF/50V | C57 | C_0805_2012Metric
10uF/10V | C58, C63 | C_0805_2012Metric
100nF/25V | C59, C66 | C_0805_2012Metric
39pF | C60 | C_0805_2012Metric
100uF/50V | C61, C69 | CP_Elec_8x10
6800pF | C62 | C_0805_2012Metric
22uF/10V | C64 | C_1210_3225Metric
47uF/10V X7R | C70, C72 | C_1210_3225Metric
10uF/50V X7R | C71 | C_1210_3225Metric
CC0805KRX7R9BB104 | C76, C78, C80 | C_0805_2012Metric
CC0805KKX7R7BB475 | C79 | C_0805_2012Metric
CC0805JRX7R9BB332 | C81, C82 | C_0805_2012Metric
D_Schottky | D1 | D_PowerDI-123
SMAJ5.0A | D2 | D_SMA
NUP2105L | D3 | SOT-23
BAV199 | D4, D5, D6, D7, D16, D17, D18, D19, D20, D21, D23, D24, D25, D26, D27, D28, D29, D30, D46, D47 | SOT-23
LED | D8, D9, D14, D15 | LED_0805_2012Metric
D | D10, D11, D12, D13 | D_SOD-323
3V6 1W (SMA) | D22 | D_SMA
SS34 | D31, D32, D33, D34, D35, D36, D39, D40 | D_SMA
1N4148W | D37, D38 | D_SOD-123
SM8S24A | D41 | D_DO-218AB
B560C | D42 | D_SMC
LED grn | D43, D44, D45 | LED_0805_2012Metric
150mA | F1 | Fuse_1812_4532Metric
3A / 63V | F2 | Fuse_1206_3216Metric
MAX9926UAEE_V+ | IC1 | QSOP-16_3.9x4.9mm_P0.635mm
ZXMS6006DT8 | IC2, IC3, IC4 | SOT153P700X170-8N
LD1117S33 | IC5 | SOT-223-3_TabPin2
74AHCT125T14-13 | IC6 | TSSOP-14_4.4x5mm_P0.65mm
TPIC8101DW | IC7 | SOIC-20W_7.5x12.8mm_P1.27mm
Conn_01x04 | J1 | PinHeader_1x04_P2.54mm_Vertical
10uH / 3.3A | L1 | L_Bourns_SRR1260
8.2uH / 5A | L2 | L_Bourns_SRR1260
BSS138 | Q5 | SOT-23
SQM120N06-3M5L | Q6 | TO-263-2
1k | R1, R17, R18, R40, R41, R51, R52, R63, R75, R92, R93, R94, R95, R96, R97, R98, R122, R124 | R_0805_2012Metric
10k | R2, R3, R4, R5, R8, R27, R31, R32, R33, R34, R35, R71, R73, R74, R78, R79, R80, R81, R89, R106, R110, R111, R113, R123 | R_0805_2012Metric
60.4R | R6, R7 | R_0805_2012Metric
0R DNP | R9, R10, R21, R22 | R_0805_2012Metric
0R | R11, R13, R19, R20 | R_0805_2012Metric
470R | R12, R14, R58, R59, R60, R61, R62, R70, R76, R77, R86, R120 | R_0805_2012Metric
10k DNP | R15, R16 | R_0805_2012Metric
10k | R23, R24, R25, R26 | R_1206_3216Metric
33 | R28, R29, R53, R54 | R_0805_2012Metric
20m | R30 | R_2512_6332Metric
18k | R36, R37, R38, R39, R42, R43, R44, R45 | R_1206_3216Metric
4.02k | R46, R47, R48, R49 | R_0805_2012Metric
100k | R50, R99, R100, R101, R102, R103, R104, R108, R109, R112 | R_0805_2012Metric
2k49 | R55, R56 | R_0805_2012Metric
2k2 | R57, R121 | R_0805_2012Metric
12k | R64, R65, R66, R82, R83, R87, R88 | R_0805_2012Metric
20k | R67, R68, R69, R84, R85 | R_0805_2012Metric
47k | R72 | R_0805_2012Metric
5k6 | R90 | R_0805_2012Metric
1M | R91 | R_0805_2012Metric
15k | R105 | R_0805_2012Metric
330k | R107 | R_0805_2012Metric
237k | R114 | R_0805_2012Metric
56k2 | R115 | R_0805_2012Metric
162k | R116 | R_0805_2012Metric
53k6 | R117 | R_0805_2012Metric
10k2 | R118 | R_0805_2012Metric
13k | R119 | R_0805_2012Metric
2k | R125 | R_0805_2012Metric
RC0805FR-071ML | R126, R131, R132 | R_0805_2012Metric
RC0805FR-07100KL | R127, R128, R129, R130 | R_0805_2012Metric
W25Q32JVSS | U2 | SOIC-8_5.3x5.3mm_P1.27mm
MCP2562-E-SN | U3 | SOIC-8_3.9x4.9mm_P1.27mm
74AHC1G32 | U4 | SOT-353_SC-70-5
ADXL343 | U5 | LGA-14_3x5mm_P0.8mm_LayoutBorder1x6y
USBLC6-2SC6 | U6 | SOT-23-6
TPS3823-33DBV | U8 | SOT-23-5
74LVC1G00 | U9 | SOT-353_SC-70-5
LMV324 | U10, U11 | SOIC-14_3.9x8.7mm_P1.27mm
DRV8434A | U12 | HTSSOP-28-1EP_4.4x9.7mm_P0.65mm_EP2.85x5.4mm_ThermalVias
BTF3050TE | U13, U14 | TO-252-5_TabPin3
LM74700-Q1 | U15 | SOT-23-6
TPS54360B-Q1 | U16 | HSOP-8-1EP_3.9x4.9mm_P1.27mm_EP2.41x3.1mm_ThermalVias
TPS7B6950-Q1 | U17 | SOT-223-3_TabPin2
74LVC1G125 | U18 | SOT-353_SC-70-5
CSTCR4M00G53-R0 | Y1 | Resonator_SMD_Murata_CSTCR_4.5x2x1.15mm

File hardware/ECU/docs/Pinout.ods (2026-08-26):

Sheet: Pinout_ori_ECU
Pin | Color | Function | Funktionsweise | Pin | Color | Function | Funktionsweise
1 | W/Bl | Coil 1 | Pull Down 12V | 35 | B/W | Ground
2 | B | Coil 2 | Pull Down 12V | 36 | W | Crank -
3 | Y | Coil 3 | Pull Down 12V | 37 | B/Y | Cam +
4 | Gr/W | Injector 4 | Pull Down 12V | 38 | N/C | - | - | O2 sensor
5 | Gr/B | Injector 3 | Pull Down 12V | 39 | N/C | - | -
6 | Gr/Y | Injector 2 | Pull Down 12V | 40 | N/C | - | -
7 | Gr/R | Injector 1 | Pull Down 12V | 41 | N/C | - | -
8 | Br | VC Solenoid | Pull Down 12V | 42 | Y/R | Fuel 12V
9 | Y/B | Fule Pump | Pull Down 12V | 43 | G | Crank +
10 | G | Coil 4 | Pull Down 12V | 44 | BR | Cam -
11 | n/c | - | - | 45 | N/C | - | - | O2 Heizung
12 | n/c | - | - | 46 | N/C | - | -
13 | n/c | - | - | 47 | N/C | - | -
14 | n/c | - | - | 48 | R | Sensor 5V
15 | Bl/R | Diagnostic (Map Select Switch) |  | 49 | P/B | TPS
16 | Bl/Y | Diagnostic |  | 50 | DG | Air Temp
17 | O/W | Switched 12V | 12V Ignition | 51 | B/BL | Water Temp
18 | B/W | Ground |  | 52 | G/Y | Static Air
19 | B/Y | Starter Relay Input | 12V when starter, 0V when clutch | 53 | N/C | - | -
20 | Bl | Neutral input | 0V when in Neutral |  | B/BR | Sensor Gound
21 | B/Br | Diagnostic Ground |  | 55 | Y/BL | Tach Out
22 | W/R | Diagnostic | 12V ECM ? | 56 | B/G | Tacho Data Stream
23 | Bl/W | Diagnostic |  | 57 | P | Gear Position
24 | Bl/B | Diagnostic |  | 58 | G/B | Map
25 | BL/G | Diagnostic |  | 59 | B | Tip Over Sensor
26 | B/W | Ground |  | 60 | O/Y | N/C | -
27 | B/W | Ground
28 | Y/G | Starter Relay Power
29 | N/C | -
30 | N/C | -
31 | N/C | -
32 | N/C | -
33 | N/C | -
34 | N/C | -

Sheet: PD
Ref | Wert / Typ | Gehäuse | Hersteller-PN | Anmerkung
U2 | TPS54202DDCR | SOT-23-6 | Texas Instruments TPS54202DDCR | 5 V/2 A Buck
L1(optimiert) | 4.7 µH, 3.5 A Isat, DCR ≤ 50 mΩ | 744773047 | Würth WE-PD 7343 | bringt <25 mV Ripple @2 A
L1 (wie Schaltplan) | 15 µH, 2 A Isat | LPS4018-153MLC | Coilcraft LPS4018 | höherer Ripple-Strom im IC, aber OK bis 1 A
C1 | 10 µF / 50 V | 1206 | Murata GRM31CR71H106KA12 | Eingang-Bulk
C44 | 0.1 µF / 50 V | 603 | Murata GRM188R71H104KA93 | VIN-HF-Bypass
C45 | 0.1 µF / 16 V | 402 | Murata GRM155R71C104KA88 | BOOT-Cap, nahe Pins 5-6
C19, C42 | 22 µF / 10 V | 805 | Murata GRM21BC8L1A226ME44 | zwei Stück in Parallel am VOUT
C43 | 10 pF NP0 | 402 | Murata GRM1555C1H100JA01 | Feed-forward (optional, aber empfohlen)
R1 | 49.9 kΩ | 603 | Vishay CRCW060349K9FKEA | oberer FB-Teiler
R2 | 13.3 kΩ | 603 | Vishay CRCW060313K3FKEA | unterer FB-Teiler ⇒ VOUT ≈ 5.02 V
R18 | 511 kΩ | 603 | Vishay CRCW0603511KFKEA | VIN-Pull-up für EN (UVLO)
R19 | 105 kΩ | 603 | Vishay CRCW0603105KFKEA | EN-Pull-down → Vstart ≈ 7.6 V, Vstop ≈ 6.6 V

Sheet: calc
Gear Position Sensor |  |  |  |  |  | Coolant Temperature Sensor
Eingang | 5 | V |  |  |  | Eingang | 5 | V
Range | 560 - 15.000 | ohm |  |  |  | Range | 0 - 5 | V
 |  |  |  |  |  | R34 | 2490
 |  |  |  |  |  | R_Sensor | 1000
Vorwiderstand | 1000 | ohm |  |  |  | R36 | 470
(R49)
 | Gear | Resistor | strom in mA | U1 in V | U2 in V
 | 1 | 560 | 3,205128205 | 3,205128205 | 1,794871795
 | 2 | 630 | 3,067484663 | 3,067484663 | 1,932515337
 | 3 | 1500 | 2 | 2 | 3
 | 4 | 2700 | 1,351351351 | 1,351351351 | 3,648648649
 | 5 | 6800 | 0,641025641 | 0,641025641 | 4,358974359
 | 6 | 15000 | 0,3125 | 0,3125 | 4,6875
Unbelasteter Spannungsteiler |  |  | Belasteter Spannungsteiler
unbelasteter Spannungsteiler |  |  | belasteter Spannungsteiler
Formel
 |  |  | Formel
Formel

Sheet: Teensy_35_>_41
Pin | Teensy 35 | Funktion | Pin | Teensy 41 | Funktion
15 | 3v3 |  | 15 | 3v3
26 | 3v3 |  | 46 | 3v3
51 | 3v3 |  | 51 | 3v3
41 | A0 | Baro | 36 | A0 | IAT
42 | A1 | Map | 37 | A1 | CLT
30 | A14 | Battery reference | 30 | A14 | Flex sensor
31 | A15 | Clutch input | 31 | A15 | Battery reference
32 | A16 | Flex sensor | 32 | A16 | Gear Position
33 | A17 | Spare 1 Sensor | 33 | A17 | Spare 2 Sensor
34 | A18 | Spare 2 Sensor | 38 | A2 | O2
35 | A19 | IAT | 39 | A3 | TPS
43 | A2 |  | 40 | A4 | Baro
36 | A20 | CLT | 41 | A5 | Map
37 | A21 | O2 | 2 | D0 | Bluetooth
38 | A22 | TPS | 3 | D1 | Bluetooth
44 | A3 / D17 |  | 12 | D10 | CS IGN Output Driver 1
45 | A4 / D18 | Cam IN | 42 | D18 | Cam IN
46 | A5 / D19 | Crank IN | 43 | D19 | Crank IN
47 | A6 |  | 44 | D22 | Spare 2 D input
48 | A7 |  | 45 | D23 | Tip Over Sensor
49 | A8 / D22 | Spare 2 D input | 16 | D24 | Boost out
50 | A9 / D23 | Spare 1 D input | 17 | D25 | fan out
2 | D0 | Bluetooth | 18 | D26 | Spare 2 out
3 | D1 | Bluetooth | 19 | D27 | IDLE out
12 | D10 | CS IGN Output Driver 1 | 20 | D28 | Spare 2 out PWM
16 | D24 | Boost out | 21 | D29 | Spare 1 out PWM
17 | D25 | Fan out | 5 | D3
18 | D26 | Idle out | 22 | D30 | EN Stepper driver
19 | D27 | Spare 2 out PWM | 23 | D31 | step stepper driver
20 | D28 | Spare 1 out PWM | 24 | D32 | dir stepper driver
21 | D29 | VTT out | 28 | D36 | Clutch input
5 | D3 | TxD Can | 6 | D4
22 | D30 | EN Stepper driver | 7 | D5 | Tacho out
23 | D31 | step stepper driver | 8 | D6 | CS Flash Storage
24 | D32 | dir stepper driver | 9 | D7 | CS Accelerometer
6 | D4 | RxD Can | 10 | D8 | Fuel pump out
7 | D5 | Tacho out | 11 | D9
8 | D6 | CS Flash Storage | 1 | GND
9 | D7 | CS Accelerometer | 34 | GND
10 | D8 | Fuel pump out | 52 | GND
11 | D9 | CS IGN Output Driver 2 | 58 | GND
1 | GND |  | 59 | GND
27 | GND |  | 47 | GNDA
39 | GND |  | 4 | MC33814-CS | CS MC33814
52 | GNDA |  | 14 | MISO
4 | MC33814-CS | CS MC33814 | 13 | MOSI
14 | MISO |  | 25 | NC
13 | MOSI |  | 26 | NC
54 | NC |  | 27 | NC
55 | NC |  | 29 | NC
56 | NC |  | 49 | NC
57 | NC |  | 60 | NC
58 | NC |  | 61 | NC
59 | NC |  | 62 | NC
60 | NC |  | 63 | NC
61 | NC |  | 64 | NC
62 | NC |  | 65 | NC
63 | NC |  | 66 | NC
64 | NC |  | 67 | NC
65 | NC |  | 53 | PROG
66 | NC |  | 54 | RESET
67 | NC |  | 35 | SCLK
68 | NC |  | 55 | USB 5v
69 | NC |  | 56 | USB D-
70 | NC |  | 57 | USB D+
71 | NC |  | 50 | Vbat
72 | NC |  | 48 | VDD
73 | NC |  | 68
74 | NC |  | 69
75 | NC |  | 70
76 | NC |  | 71
77 | NC |  | 72
78 | NC |  | 73
79 | NC |  | 74
80 | NC |  | 75
81 | NC |  | 76
82 | NC |  | 77
83 | NC |  | 78
84 | NC |  | 79
85 | NC |  | 80
86 | NC |  | 81
28 | PROG |  | 82
29 | RESET |  | 83
40 | SCLK |  | 84
25 | Vbat |  | 85
53 | VDD |  | 86

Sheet: Dropbear_v2_-_Busa
Pin | Teensy 41 | Funktion | Dropbear V2 | Funktion
1 | GND
2 | D0 | Bluetooth
3 | D1 | Bluetooth
4 | MC33814-CS | CS MC33814
5 | D3
6 | D4
7 | D5 | Tacho out
8 | D6 | CS Flash Storage | CS Flash Storage
9 | D7 | CS Accelerometer
10 | D8 | Fuel pump out
11 | D9 |  | CS IGN Output Driver 2
12 | D10 | CS IGN Output Driver 1 | CS IGN Output Driver 1
13 | MOSI
14 | MISO
15 | 3v3
16 | D24 | Boost out
17 | D25 | fan out
18 | D26 | Spare 2 out
19 | D27 | IDLE out
20 | D28 | Spare 2 out PWM
21 | D29 | Spare 1 out PWM
22 | D30 | EN Stepper driver
23 | D31 | step stepper driver
24 | D32 | dir stepper driver
25 | NC
26 | NC
27 | NC
28 | D36 | Clutch input
29 | NC
30 | A14 | Flex sensor
31 | A15 | Battery reference
32 | A16 | Gear Position
33 | A17 | Spare 2 Sensor
34 | GND
35 | SCLK
36 | A0 | IAT
37 | A1 | CLT
38 | A2 | O2
39 | A3 | TPS
40 | A4 | Baro
41 | A5 | Map
42 | D18 | Cam IN | Crank IN
43 | D19 | Crank IN | Cam IN
44 | D22 | Spare 2 D input
45 | D23 | Tip Over Sensor
46 | 3v3
47 | GNDA
48 | VDD
49 | NC
50 | Vbat
51 | 3v3
52 | GND
53 | PROG
54 | RESET
55 | USB 5v
56 | USB D-
57 | USB D+
58 | GND
59 | GND
60 | NC
61 | NC
62 | NC
63 | NC
64 | NC
65 | NC
66 | NC
67 | NC
68
69
70
71
72
73
74
75
76
77
78
79
80
81
82
83
84
85
86

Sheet: Sensor-Module
Pin | Funktion | kabelstrang | Connector_type | Connector_pin
1 | GND | 1 | 6447232 -3
2 | 12V-SW | 1 | 6447232 -3
3 | CAN_H | 1 | 6447232 -3
4 | CAN_L | 1 | 6447232 -3
5 | Exhaust_Temp_1+ | 2 | 6447232 -3
6 | Exhaust_Temp_1- | 2 | 6447232 -3
7 | Exhaust_Temp_2+ | 2 | 6447232 -3
8 | Exhaust_Temp_2- | 2 | 6447232 -3
9 | Exhaust_Temp_3+ | 2 | 6447232 -3
10 | Exhaust_Temp_3- | 2 | 6447232 -3
11 | Exhaust_Temp_4+ | 2 | 6447232 -3
12 | Exhaust_Temp_4- | 2 | 6447232 -3
13 | Oil_Pressure+ | 3 | 6447232 -3
14 | Oil_Pressure- | 3 | 6447232 -3
15 | Oil_Pressure_Signal | 3 | 6447232 -3
16 | Fuel_Pressure+ | 4 | 6447232 -3
17 | Fuel_Pressure- | 4 | 6447232 -3
18 | Fuel_Pressure_Signal | 4 | 6447232 -3
19 | Oil_Temp+ | 3 | 6447232 -3
20 | Oil_Temp- | 3 | 6447232 -3
21 | LLK_Water_Temp1+ | 5 | 6447232 -3
22 | LLK_Water_Temp1- | 5 | 6447232 -3
23 | LLK_Water_Temp2+ | 5 | 6447232 -3
24 | LLK_Water_Temp2- | 5 | 6447232 -3
25 | Exhaust_Pressure+ | 2 | 6447232 -3
26 | Exhaust_Pressure- | 2 | 6447232 -3
27 | Exhaust_Pressure_Signal | 2 | 6447232 -3
28 | Quickshift-Pull+ | 6 | 6447232 -3
29 | Quickshift-Pull- | 6 | 6447232 -3
30 | Quickshift-Push+ | 6 | 6447232 -3
31 | Quickshift-Push- | 6 | 6447232 -3
32 | Intercooler-Fan+ | 5 | 6447232 -3
33 | Intercooler-Fan- | 5 | 6447232 -3
Kabelstrang | Adern
1 | 4
2 | 11
3 | 5
4 | 3
5 | 6
6 | 4

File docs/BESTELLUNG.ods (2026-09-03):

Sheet: ECU
ECU Parts List
Cost |  | 244,97 €
DigiKey |  |  | Cost | 101,48 €
Item | Qty | Reference(s) | Value | LibPart | Footprint | Datasheet | DNP | Allied_Number | Arrow Part Number | Arrow Price/Stock | Datasheet | Description | Digikey Part Number | Footprint | Height | Manufacturer_Name | Manufacturer_Part_Number | Mouser Part Number | Mouser Price/Stock | RS Part Number | RS Price/Stock | Sim.Device | Sim.Library | Sim.Pins | Tolerance | URL | Voltage
2 | 1 | BT1 | Battery_Cell | Device:Battery_Cell | 2999:BAT_2999 | ~ |  |  |  |  | ~ | Single-cell battery | 36-2999-ND | 2999:BAT_2999 |  | Keystone | 2999 |  |  |  |  |  |  |  |  | https://www.digikey.com.au/product-detail/en/keystone-electronics/2999/36-2999-ND/2137863
3 | 14 | C3, C9, C12, C13, C14, C20, C21, C23, C26, C32, C34, C37, C40, C41 | 0.1uF | Device:C | Capacitor_SMD:C_0805_2012Metric | ~ |  |  |  |  | ~ | Unpolarized capacitor | 311-1140-1-ND | Capacitor_SMD:C_0805_2012Metric |  | Yageo | CC0805KRX7R9BB104 |  |  |  |  |  |  |  |  | https://www.digikey.com.au/product-detail/en/yageo/CC0805KRX7R9BB104/311-1140-1-ND/303050
4 | 4 | C4, C7, C29, C30 | 0.01uF | Device:C | Capacitor_SMD:C_0805_2012Metric | ~ |  |  |  |  | ~ | Unpolarized capacitor | 311-1136-1-ND | Capacitor_SMD:C_0805_2012Metric |  | Yageo | CC0805KRX7R9BB103 |  |  |  |  |  |  |  |  | https://www.digikey.com/product-detail/en/yageo/CC0805KRX7R9BB103/311-1136-1-ND/303046
5 | 1 | C5 | 4700pF | Device:C | Capacitor_SMD:C_0805_2012Metric | ~ |  |  |  |  | ~ | Unpolarized capacitor | 311-1133-1-ND | Capacitor_SMD:C_0805_2012Metric |  | Yageo | CC0805KRX7R9BB472 |  |  |  |  |  |  |  |  | https://www.digikey.com/product-detail/en/yageo/CC0805KRX7R9BB103/311-1136-1-ND/303046
6 | 2 | C6, C8 | 1nF | Device:C | Capacitor_SMD:C_0805_2012Metric | ~ |  |  |  |  | ~ | Unpolarized capacitor | 399-16591-1-ND | Capacitor_SMD:C_0805_2012Metric |  | Kemet | C0805C102J5HACAUTO |  |  |  |  |  |  |  |  | https://www.digikey.com/product-detail/en/kemet/C0805C102J5HACAUTO/399-16591-1-ND/7943643
7 | 2 | C10, C11 | 1uF | Device:C | Capacitor_SMD:C_0805_2012Metric | ~ |  |  |  |  | ~ | Unpolarized capacitor | 311-1365-1-ND | Capacitor_SMD:C_0805_2012Metric |  | Yageo | CC0805KKX7R7BB105 |  |  |  |  |  |  |  |  | https://www.digikey.com/product-detail/en/yageo/CC0805KKX7R7BB105/311-1365-1-ND/2103149
8 | 2 | C15, C18 | 270nF | Device:C | Capacitor_SMD:C_0805_2012Metric | ~ |  |  |  |  | ~ | Unpolarized capacitor | 311-4268-1-ND | Capacitor_SMD:C_0805_2012Metric |  | Yageo | CC0805JRX7R7BB274 |  |  |  |  |  |  |  |  | https://www.digikey.com.au/product-detail/en/yageo/CC0805JRX7R7BB274/311-4268-1-ND/8025357
9 | 5 | C16, C17, C24, C25, C28 | 0.22uF | Device:C | Capacitor_SMD:C_0805_2012Metric | ~ |  |  |  |  | ~ | Unpolarized capacitor | 1276-1284-1-ND | Capacitor_SMD:C_0805_2012Metric |  | Samsung | CL21B224KOCNNNC |  |  |  |  |  |  |  |  | https://www.digikey.com/product-detail/en/samsung-electro-mechanics-america-inc/CL21B224KOCNNNC/1276-1284-1-ND/3889370
10 | 1 | C27 | 100uF | Device:C | Capacitor_SMD:C_1206_3216Metric | ~ |  |  |  |  | ~ | Unpolarized capacitor | 1276-1782-1-ND | Capacitor_SMD:C_1206_3216Metric |  | Samsung | CL31A107MQHNNNE |  |  |  |  |  |  |  |  | https://www.digikey.com.au/product-detail/en/samsung-electro-mechanics/CL31A107MQHNNNE/1276-1782-1-ND/3889868
11 | 1 | C31 | 100uF | Device:CP | Capacitor_SMD:CP_Elec_6.3x7.7 |  |  |  |  |  |  |  | P124821CT-ND | Capacitor_SMD:CP_Elec_6.3x7.7 |  | Panasonic | EEE-FT1V101AV |  |  |  |  |  |  |  |  | https://www.digikey.com.au/product-detail/en/panasonic-electronic-components/EEE-FT1V101AV/P124821CT-ND/10290763
12 | 2 | C33, C36 | 47uF | Device:CP | Capacitor_Tantalum_SMD:CP_EIA-3528-21_Kemet-B |  |  |  |  |  |  |  | 478-1692-1-ND | Capacitor_Tantalum_SMD:CP_EIA-3528-21_Kemet-B |  | AVX | TAJB476K006RNJ |  |  |  |  |  |  |  |  | https://www.digikey.com/product-detail/en/avx-corporation/TAJB476K006RNJ/478-1692-1-ND/564724 | 10V
13 | 1 | C35 | 22uF | Device:CP | Capacitor_SMD:CP_Elec_4x5.4 |  |  |  |  |  |  |  | EEE-1CA220WR | Capacitor_SMD:CP_Elec_4x5.4 |  | Panasonic | PCE3882CT-ND |  |  |  |  |  |  |  |  | https://www.digikey.com.au/product-detail/en/panasonic-electronic-components/EEE-1CA220WR/PCE3882CT-ND/766258 | 10v
14 | 2 | C38, C39 | 33uF | Device:CP | Capacitor_SMD:CP_Elec_6.3x7.7 |  |  |  |  |  |  |  | PCE3925CT-ND | Capacitor_SMD:CP_Elec_6.3x7.7 |  | Panasonic | EEE-1HA330XP |  |  |  |  |  |  |  |  | https://www.digikey.com.au/product-detail/en/panasonic-electronic-components/EEE-1HA330XP/PCE3925CT-ND/766301 | 50V
15 | 8 | D1, D2, D5, D7, D18, D19, D21, D22 | LED | Device:LED | LED_SMD:LED_0805_2012Metric | ~ |  |  |  |  | ~ | Light emitting diode | SML-H12D8TT86CCT-ND | LED_SMD:LED_0805_2012Metric |  | Rohm Semiconductor | SML-H12D8TT86C |  |  |  |  |  |  |  |  | https://www.digikey.com.au/product-detail/en/rohm-semiconductor/SML-H12D8TT86C/SML-H12D8TT86CCT-ND/9090486
16 | 1 | D3 | 1N4148WT | Diode:1N4148WT | Diode_SMD:D_SOD-523 | https://www.diodes.com/assets/Datasheets/ds30396.pdf |  |  |  |  | https://www.diodes.com/assets/Datasheets/ds30396.pdf | 75V 0.15A Fast switching Diode, SOD-523 |  | Diode_SMD:D_SOD-523 |  |  |  |  |  |  |  | D |  | 1=K 2=A
17 | 10 | D9, D11, D13, D15, D25, D26, D28, D29, D30, D31 | D | Device:D | Diode_SMD:D_SOD-323 | ~ |  |  |  |  | ~ | Diode | 1N4448WXTPMSCT-ND | Diode_SMD:D_SOD-323 |  | MCC | 1N4448WX-TP |  |  |  |  |  |  |  |  | https://www.digikey.com/product-detail/en/micro-commercial-co/1N4448WX-TP/1N4448WXTPMSCT-ND/789338
18 | 2 | D27, D37 | D_Schottky | Device:D_Schottky | Diode_SMD:D_PowerDI-123 | ~ |  |  |  |  | ~ | Schottky diode | DFLS2100-7DICT-ND | Diode_SMD:D_PowerDI-123 |  | Diodes Inc. | DFLS2100-7 |  |  |  |  |  |  |  |  | https://www.digikey.com/product-detail/en/diodes-incorporated/DFLS2100-7/DFLS2100-7DICT-ND/3451552
19 | 1 | D32 | D_TVS | Device:D_Zener | Diode_SMD:D_SMB | ~ |  |  |  |  | ~ | Zener diode | SMBJ40A-QCT-ND | Diode_SMD:D_SMB |  | Bournes Inc. | SMBJ40A-Q |  |  |  |  |  |  |  |  | https://www.digikey.com.au/product-detail/en/bourns-inc/SMBJ40A-Q/SMBJ40A-QCT-ND/10222718
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

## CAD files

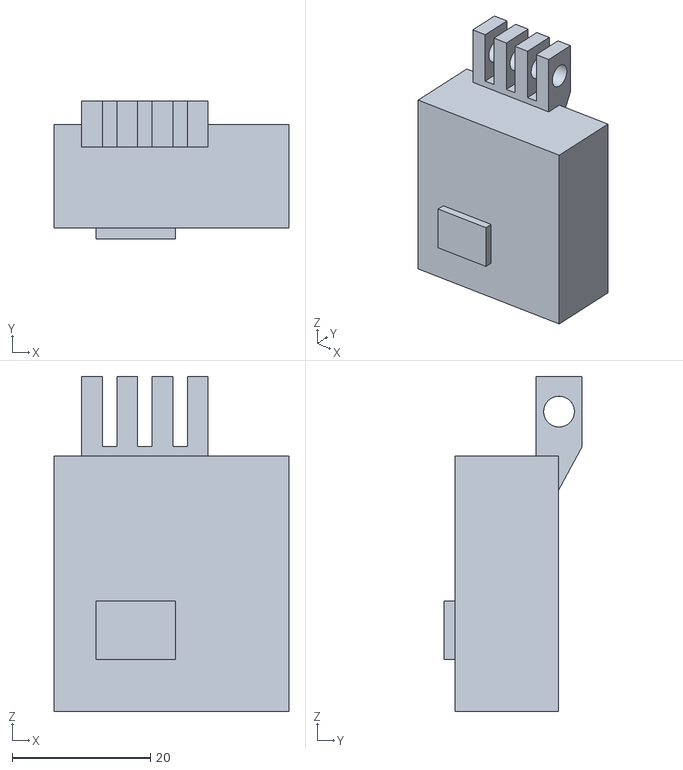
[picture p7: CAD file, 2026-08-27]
hardware/ECU/case/Hayabusa ECU v3 Kühlkörper.stl
34.0 x 20.0 x 48.5

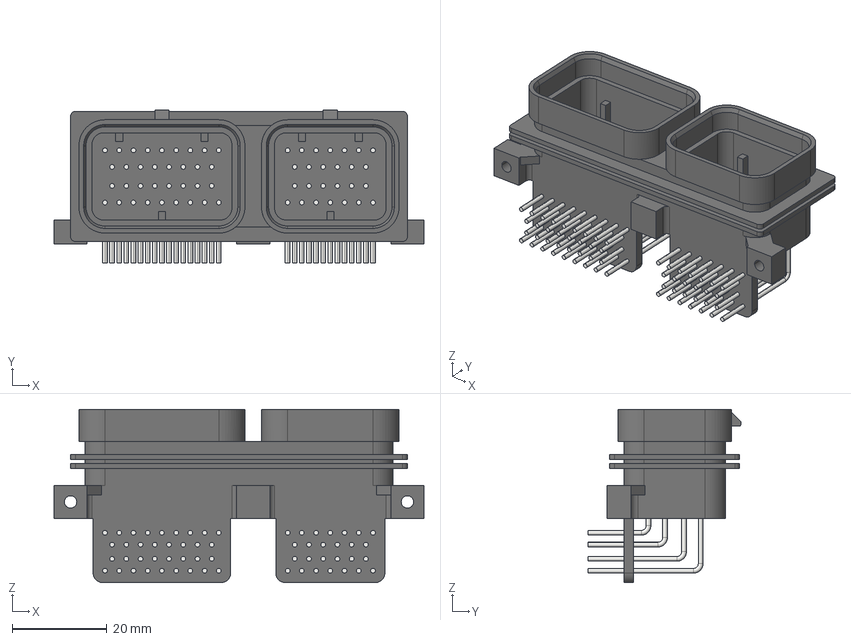
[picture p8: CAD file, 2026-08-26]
hardware/ECU/case/v1/Connector_color.stp
78.0 x 32.1 x 36.5 mm

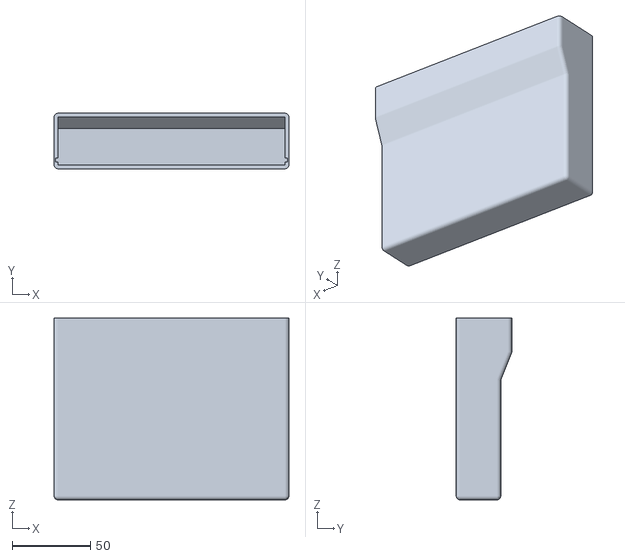
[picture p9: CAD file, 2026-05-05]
hardware/ECU/case/case.stl
150.0 x 35.5 x 116.0

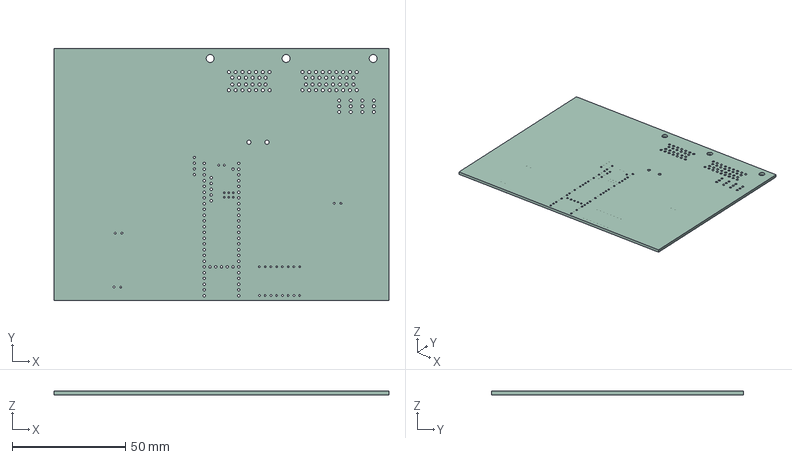
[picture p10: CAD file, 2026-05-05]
hardware/ECU/case/v1/circuit board.step
148.0 x 111.5 x 1.60 mm

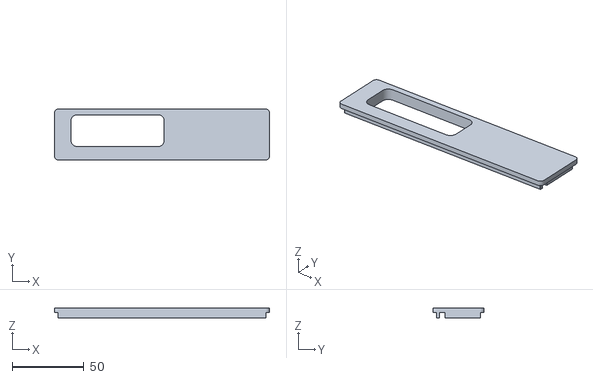
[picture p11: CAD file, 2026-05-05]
hardware/ECU/case/hood.stl
150.0 x 35.5 x 7.00

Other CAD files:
hardware/ECU/case/v1/Connector.stp
hardware/ECU/case/Hayabusa ECU Case.f3d

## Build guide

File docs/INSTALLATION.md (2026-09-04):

# Installationsanleitung

Einbau der Gen1 Hayabusa ECU Rev 3 in eine Suzuki GSX1300R Hayabusa **1999** (Gen 1,
frühes 8-Zahn-Kurbelwellenrad). Die Rev 3 sitzt am Serienstecker; der Kabelbaum bleibt.
Werte und Verfahren für den ersten Start stehen in `tune/Hayabusa-R3/README.md`, dieses
Dokument beschreibt Einbau, Verkabelung und Inbetriebnahme bis zum ersten Zündfunken.

## Sicherheitshinweise

**Warnung**: Ein selbst gebautes Steuergerät greift in Zündung und Kraftstoffzufuhr ein.
Fehler führen zu Motorschaden oder Ausfall während der Fahrt. Im Geltungsbereich der StVZO
erlischt die Betriebserlaubnis, solange kein Gutachten vorliegt.

Vor der Installation:
- Serien-Steuergerät und Kabelbaum unverändert aufbewahren (Rückbau möglich).
- Werkstatthandbuch 1999–2001 (GSX1300R X/Y/K1) griffbereit.
- Feuerlöscher, Notaus für die Kraftstoffpumpe, Laptop mit TunerStudio.
- Innovate LC-2 mit LSU 4.9 eingebaut und funktionsfähig, sonst kein erster Start.

## Werkzeuge

- Multimeter, Oszilloskop (für Kurbel- und Nockensignal), Blitzpistole
- Drehmomentschlüssel (Sensoren, Gehäuse), Crimpwerkzeug, Lötstation
- TunerStudio MS Ultra (VE Analyze Live), PlatformIO für die Firmware

## Steuergerät

### Position und Stecker

Das Serien-Steuergerät der Gen 1 sitzt unter der Sitzbank rechts. Die Rev 3 übernimmt den
Serienstecker (TE 6437288-3, 60-polig) mit der Belegung des Serien-Steuergeräts. Alle
Pins: [HARDWARE.md](HARDWARE.md), Abschnitt „Steckerbelegung J2".

### Was die Serie nicht hat

| Signal | J2 | Anschluss |
|---|---|---|
| Lambda (LC-2 Analogausgang 1, 0–3,3 V) | 38 | LC-2 Analogmasse an J2.54 Sensormasse, LC-2 mit eigener Sicherung an geschaltetem 12 V |
| Lambdaheizung | 46 | **offen lassen**, der LC-2 heizt selbst; der Ausgang schaltet 3 s nach Drehzahl > 0 auf 12 V |
| CAN zum Sensor-Modul | 14 / 15 | 500 kbit/s, verdrillt, Abschluss am Modul |
| USB | 16 / 24 + Datenleitungen | Blatt Comms im Schaltplan |
| Lüfter | 29 | nur wenn der Lüfter von der ECU geschaltet werden soll (Tune: Aus, Serien-Thermoschalter bleibt) |
| Ladedrucksteller, Spare-Ausgang, Flex, Spare-Digital | 30, 47, 39, 60 | unbenutzt |

### Kanal- und Zylinderzuordnung

Der Stecker ist nach Zylindernummer belegt (Spulen J2.1/2/3/10, Düsen J2.7/6/5/4 =
Zylinder 1/2/3/4). Speeduino feuert seine Kanäle in der Zündfolge 1-2-4-3; die Firmware
ordnet Kanal 3 dem Zylinder 4 und Kanal 4 dem Zylinder 3 zu. **Am Kabelbaum nichts
tauschen.** Kontrolle im Hardware-Test: IGN3 muss die Spule von Zylinder 4 klicken lassen.

Zylinder 1 ist links (Generatorseite), Zylinder 4 rechts (Kupplungsseite).

### Sensoren der Serie, wie sie die Rev 3 sieht

| Sensor | J2 | Beschaltung ECU | Kennwerte |
|---|---|---|---|
| Kurbelwelle (VR, 8 Zähne auf dem Generatorrotor) | 43 (+) / 36 (−) | MAX9926 Kanal 1 | 180–280 Ω |
| Nockenwelle (VR, ein Stift auf der Einlassnocke) | 37 (+) / 44 (−) | MAX9926 Kanal 2 | 0,9–1,3 kΩ, sitzt neben Spule 1 (Störungen) |
| Saugrohrdruck IAP 18590-81A00 | 58 | Teiler 12 k/20 k | ≈ 3,6 V bei 100 kPa |
| Atmosphärendruck AP 18590-81A00 | 52 | Teiler 12 k/20 k | im Tune nicht genutzt |
| Drosselklappe | 49 | Teiler 12 k/20 k | ≈ 1,1 V zu, 4,3 V offen |
| Kühlmittel, Ansaugluft (NTC) | 51, 50 | 2,49 kΩ an 3,3 V | 2,3–2,6 kΩ bzw. 2,2–2,7 kΩ bei 20 °C |
| Gangsensor | 57 | 1 kΩ, Teiler | Widerstandsleiter gegen Masse |
| Kippschalter | 59 | Komparator | ≈ 2,5 V aufrecht (Gen-1-Typ 60–64 kΩ) |
| Neutral, Kupplung | 20, 19 | Teiler 10 k/10 k an 3,3 V | Schalter nach Masse; Low-Pegel nur 1,65 V (Befund 1) |
| Sensorversorgung | 48 (+5 V), 54 (Masse) | TPS7B6950, Polyfuse 150 mA | |

Die Kurbelsensor-Leitungen teilen sich in der Serie den Kabelbaum mit dem Generator.
Bei Sync-Problemen die zwei Adern verdrillt und getrennt vom Generatorkabel führen.

## Firmware

```bash
git submodule update --init
cd speeduino
pio run -e teensy41_hayabusa -t upload
```

Branch `Hayabusa/ECU-R3` mit den Korrekturen vom September 2026 (Kanalzuordnung,
Batteriespannung, INI). Details in [SOFTWARE.md](SOFTWARE.md).

## TunerStudio

1. Projekt `tune/Hayabusa-R3` öffnen. *Project Properties → Settings*: „Hayabusa multi map
   switching = Enabled". COM-Port setzen (`project.properties` steht auf COM1).
2. Erster Verbindungsaufbau mit leerem Kennfeldspeicher: TunerStudio meldet, dass Controller
   und Datei abweichen → **Datei auf den Controller schreiben**, dann *Burn*.
3. ECU aus- und einschalten. Erst jetzt ist Board 57 aktiv. Kontrolle: FI-Lampe geht nach
   2 s aus, *Engine Constants* zeigt „Gen1 Hayabusa ECU R3".
4. Kalibrierungen senden (sie liegen im Kennfeldspeicher, nicht in der .msq):

| Kalibrierung | Einstellung |
|---|---|
| *Calibrate Thermistor Tables*, CLT | Bias 2490 Ω; 20 °C 2450 Ω, 50 °C 811 Ω, 80 °C 318 Ω |
| *Calibrate Thermistor Tables*, IAT | Bias 2490 Ω; 20 °C ≈ 2450 Ω, restliche Punkte messen oder CLT-Kurve übernehmen |
| *Calibrate TPS* | geschlossen und Vollgas am Fahrzeug; Startwerte im Tune 53 / 208 ADC |
| *Calibrate AFR Table* | Preset „Innovate LC-1 / LC-2 Default", LC-2 Analogausgang 1 im LM Programmer auf 0,00 V = AFR 7,35 … 3,30 V = AFR 22,39 |
| MAP | fest im Tune: 10 kPa bei 0 V, 142 kPa bei Vollausschlag (Serien-IAP hinter 12 k/20 k). Bei Zündung an muss der Umgebungsdruck stehen, sonst `mapMax` anpassen |

## Inbetriebnahme

### Statischer Test, Motor aus

| Größe | Sollwert |
|---|---|
| Batteriespannung in TunerStudio | wie Multimeter (±0,3 V) |
| Sensor-5 V an J2.48 | 4,9–5,1 V |
| MAP | Umgebungsdruck 95–102 kPa |
| TPS | 0 % zu, 100 % offen, ohne Sprünge |
| CLT, IAT | Umgebungstemperatur; −40 °C = Kabelbruch oder fehlende Kalibrierung |
| AFR (LC-2 warm, Sonde in Luft) | ≥ 20 |
| Kippschalter | FI-Lampe aus, Hardware-Test feuert; sonst Polarität (`HAYABUSA_TIPOVER_INVERTED`) |

*Tools → Test Output Hardware*: IGN1 → Spule Zylinder 1, IGN2 → 2, **IGN3 → Zylinder 4,
IGN4 → Zylinder 3**, Düsen analog. Kerzenstecker dabei auf gemasseten Kerzen.

### Trigger, ohne Kraftstoff

Kraftstoffpumpen-Sicherung ziehen oder Düsen abstecken.

1. *Tools → Tooth Logger* und *Composite Logger* beim Anlassen: 8 Zähne je Umdrehung, ein
   Nockenpuls je zwei Umdrehungen, Sync stabil, Sync Loss 0. Springt der Sync, zuerst die
   Anlasserdrehzahl vergleichmäßigen (Kerzen raus), dann Filter Off oder Flanken FALLING
   testen.
2. Fixed Timing auf 0° stellen, Kerzen eingebaut, Blitzpistole an Zylinder 1, anlassen: die
   T-Marke im Schauloch des Anlasserdeckels (rechte Kurbelseite) muss stehen. Trigger-Winkel
   so lange ändern, bis sie steht (Startwert 350, Alternative 160). Danach Fixed Timing
   zurück auf 10°, *Burn*.

### Erster Start

Feuerlöscher, Notaus, LC-2 im Blick. Weiter nach `tune/Hayabusa-R3/README.md`, Abschnitt
„Erster Start und danach": Leerlaufgemisch nachziehen, Zündzeitpunkt bei laufendem Motor
prüfen, Fixed Timing aus, später Sequential und Begrenzer anheben.

## Störungssuche

| Symptom | Prüfen |
|---|---|
| Keine Drehzahl beim Anlassen | Tooth Logger; Kurbelsignal am Oszilloskop (> 3 V Spitze beim Anlassen); Flanke; Sensorwiderstand 180–280 Ω |
| Drehzahl, aber kein Sync | Nockensignal (> 0,7 V); Störungen von Spule 1; Nockenleitung getrennt führen |
| Sync, aber kein Funke | FI-Lampe an = Freigabe fehlt (Kippschalter, Watchdog); Hardware-Test |
| Funke, aber kein Kraftstoff | Pumpe läuft 3 s beim Einschalten? `tpsflood` 90 %; Düsen klicken im Hardware-Test |
| Läuft nur auf zwei Zylindern, Fehlzündungen | Kanalzuordnung: IGN3 muss Zylinder 4 sein; Firmware-Stand prüfen |
| Startet in Sequential nicht mehr | Nockenphase 360° verkehrt: Trigger-Winkel ±360 |
| −40 °C / 130 °C | Kabelbruch / Kurzschluss oder fehlende Thermistor-Kalibrierung |
| Batteriespannung ≈ 18 V | Firmware ohne Board-57-Skalierung |

## Rückbau

Serien-Steuergerät wieder anstecken, LC-2 kann bleiben (Analogausgang dann unbenutzt),
Heizerausgang J2.46 war ohnehin offen.

---

**Version**: 4.0
**Stand**: September 2026

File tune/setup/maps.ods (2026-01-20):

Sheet: VE_org
TPS fuelmap |  |  |  |  |  |  |  |  |  |  |  |  |  |  |  |  |  |  |  |  |  |  |  |  | TPS fuelmap
 | 0 | 0,6 | 1,2 | 1,9 | 2,5 | 3,1 | 3,7 | 4,4 | 5,6 | 6,8 | 8,1 | 9,3 | 10,6 | 15,5 | 20,5 | 25,5 | 30,5 | 40,4 | 50,4 | 60,3 | 70,3 | 90,2 | 100 | TPS % | RPM | 0.0 | 6.7 | 13.3 | 20.0 | 26.7 | 33.3 | 40.0 | 46.7 | 53.3 | 60.0 | 66.7 | 73.3 | 80.0 | 86.7 | 93.3 | 100.0
800 | 42 | 43 | 65 | 74 | 84 | 87 | 94 | 97 | 106 | 114 | 117 | 123 | 123 | 125 | 129 | 133 | 134 | 137 | 137 | 138 | 142 | 144 | 144 |  | 800 | 42 | 113 | 124 | 129 | 133 | 135 | 137 | 137 | 137 | 138 | 141 | 142 | 143 | 144 | 144 | 144
1000 | 42 | 43 | 65 | 74 | 84 | 87 | 94 | 97 | 106 | 114 | 117 | 123 | 123 | 125 | 129 | 133 | 134 | 137 | 137 | 138 | 142 | 144 | 144 |  | 1600 | 36 | 90 | 115 | 127 | 129 | 129 | 129 | 129 | 129 | 130 | 130 | 131 | 131 | 132 | 133 | 135
1200 | 38 | 37 | 58 | 70 | 76 | 82 | 86 | 88 | 97 | 102 | 108 | 114 | 119 | 127 | 127 | 127 | 123 | 122 | 123 | 124 | 128 | 129 | 133 |  | 2400 | 29 | 78 | 97 | 111 | 123 | 126 | 127 | 128 | 128 | 129 | 130 | 130 | 131 | 132 | 135 | 141
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

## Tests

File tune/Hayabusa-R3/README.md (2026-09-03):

# Hayabusa-R3 — TunerStudio-Projekt für die Gen1 Hayabusa ECU Rev 3

Basisabstimmung für die Suzuki GSX1300R Hayabusa **Baujahr 1999** (Gen 1, Modell X,
originales 8-Zahn-Kurbelwellenrad) mit dem Eigenbau-Steuergerät Rev 3 (Board 57
„Gen1 Hayabusa ECU R3", Speeduino-Fork `HasiKe/speeduino`, Branch `Hayabusa/ECU-R3`, lokal `Hayabusa/ECU-R3-v2`).

Stand: 2026-09-03. Die Kennfelder stammen aus dem originalen Steuergerät
(`tune/setup/maps.ods`), alle übrigen Werte sind Startwerte für die Inbetriebnahme.
**Der Motor ist mit diesem Tune noch nie gelaufen.** Trigger-Winkel, TPS-Kalibrierung,
Thermistor- und Lambda-Kalibrierung müssen am Fahrzeug bestimmt werden, siehe
Abschnitt „Vor dem ersten Start".

## Dateien

| Datei | Inhalt |
|---|---|
| `CurrentTune.msq` | Tune, Signatur `speeduino 202504-dev`, 21 Seiten (Kennfeldsätze 1–4) |
| `projectCfg/mainController.ini` | TunerStudio-INI, Kopie von `speeduino/reference/speeduino.ini` des Fork-Stands unten |
| `projectCfg/project.properties` | Projekt-Einstellungen, Setting-Groups: `mcu_teensy`, `HAYABUSA_MULTIMAP`, `CELSIUS`, `AFR`, `pressure_bar`, `enablehardware_test`, `resetcontrol_standard` |
| `tools/gen_tune.py` | Generator: erzeugt `CurrentTune.msq` und kopiert die INI aus dem Submodul. Parameter im Kopf der Datei (`P`), Einzelwerte im Dict `E` |
| `tools/stockmaps.py` | liest die Stock-Kennfelder aus `maps.ods`, repariert die Achsen-Tippfehler, interpoliert bilinear |
| `tools/iniparse.py`, `tools/msqinfo.py`, `tools/dumptables.py` | INI-Parser, MSQ-Leser, Tabellenanzeige |
| `tools/base_tune_Busa_2026-02-02.msq` | altes TunerStudio-Tune als Format-Gerüst und Quelle für inaktive Einstellungen (Werte, die auf den Motor wirken, kommen nicht von dort) |

Neu erzeugen nach Änderung an Parametern oder INI:

```bash
python3 tune/Hayabusa-R3/tools/gen_tune.py
python3 tune/Hayabusa-R3/tools/dumptables.py tune/Hayabusa-R3/CurrentTune.msq veTable advTable1
```

Der Generator prüft jeden Wert gegen die INI (Optionsliste, Wertebereich, Auflösung) und
bricht bei Fehlern ab. Die Projekt-INI muss immer byteidentisch mit der INI sein, mit
der das Tune erzeugt wurde, sonst werden Konstanten falsch abgelegt.

## Voraussetzung: Firmware-Stand

Das Tune setzt den Fork-Stand mit folgenden Korrekturen voraus (Branch `Hayabusa/ECU-R3`,
lokal `Hayabusa/ECU-R3-v2`, Commits 7e55b2d9 und 13a7e98d vom 2026-09-03). Ohne den ersten Punkt läuft der Motor nicht richtig.

1. **Zylinderzuordnung** in `getHayabusaR3Mapping()`: Speeduino feuert Kanal 3 bei 360° und
   Kanal 4 bei 540° Kurbelwinkel. J2 folgt dem Stock-Pinout (Coil/Injector 1–4 nach
   Zylindernummer), die Zündfolge ist 1-2-4-3. Die Firmware legt deshalb Kanal 3 auf
   Zylinder 4 (J2.10 Spule, J2.4 Düse) und Kanal 4 auf Zylinder 3 (J2.3 Spule, J2.5 Düse).
   Der Kabelbaum bleibt nach Zylindernummer verdrahtet. Zylinder 1 ist links
   (Generatorseite).
2. **Batteriespannung**: A15 hängt an 47k/10k, Endwert 18,8 V statt 24,5 V. Ohne die
   Korrektur zeigt die ECU 14,0 V als 18,2 V und kürzt Dwell und Düsen-Totzeit.
3. **INI**: `ignTrim1..8` lagen auf Seite 6 über `airDenRates`/`boostFreq`/`vvtFreq`/
   `idleFreq`/Launch-Byte (Upstream-Fehler) und stehen jetzt auf Seite 13; Load-Achsen der
   Kennfeldsätze 3/4 folgen dem Last-Algorithmus (TPS) statt fester kPa-Skalierung;
   `boostTable3/4` mit Skalierung 2,0.

Bauen und flashen:

```bash
cd speeduino && pio run -e teensy41_hayabusa -t upload
```

## Herkunft und Umrechnung der Kennfelder

- Quelle `tune/setup/maps.ods`: Blatt `VE_org`, Block „TPS fuelmap" (23 TPS-Spalten 0–100 %,
  42 Drehzahlzeilen 800–12800) und Blatt `IGN_org`, Block „Ignitionmap" (23 × 36, 800–14800).
  Tippfehler in den Drehzahlachsen werden vom Generator korrigiert (1200→12000 in beiden
  Kraftstoffblöcken, 200→2000 und 1400→14000 in der Zündung). Das Blatt `ING` ist **nicht**
  die Stock-Zündung (bis zu 8° mehr Frühzündung bei niedriger Drehzahl, Herkunft unklar)
  und wird nicht verwendet. Die Maps stammen aus ECUeditor, also vom 32-bit-Steuergerät
  der Modelle 2002–2007; der Motor ist mechanisch gleich.
- **VE-Tabelle**: Stock-TPS-Map bilinear auf die neuen Achsen interpoliert und mit
  120/205 = 0,585 skaliert (Maximum 205 → 120 %). Die Zellen 0–4 % TPS unter 2000 rpm sind
  auf 40 gesetzt: dort benutzt das Stock-Steuergerät die IAP-Map (Umschaltpunkt 11 % TPS),
  die TPS-Werte sind dort nicht aussagekräftig. Erwartete Leerlauf-Pulsbreite ca. 2,7 ms je
  Einspritzung, eher fett.
- **Zündung**: `IGN_org` interpoliert, minus 3° in allen Zellen mit Last ≥ 25 % TPS und
  ≥ 2000 rpm (Verdichtung 12:1 statt 11:1, noch kein Klopfsensor). Leerlauf- und
  Schubzellen unverändert (9° bei 800 rpm).
- **reqFuel 8,3 ms**: 1299 cc, 4 Zylinder, AFR 14,7, Düsen 257 cc/min bei 3 bar
  (Stock 15710-24F00, 24,5 lb/h). Die Firmware halbiert den Wert für Semi-Sequential
  selbst; beim Wechsel auf Sequential bleibt 8,3 stehen. Flowbench-Berichte liegen bei
  240–280 cc/min; sind die Düsen größer, wird das Gemisch fetter, nicht magerer.
- **Achsen**: Kraftstoff 800/1200/1600/2000/2400/2800/3400/4000/4800/5600/6400/7200/8000/
  9200/10400/12000 rpm, Zündung 800/1200/1600/2000/2400/2800/3200/3600/4000/4800/5600/6400/
  7200/8400/10000/12000 rpm, Last beide 0/2/4/6/8/10/13/16/20/25/30/40/50/60/75/100 % TPS.
- **Kennfeldsätze 2–4** sind identische Kopien von Satz 1. Wahl beim Einschalten mit
  Vollgas + Kupplung, siehe `speeduino/HAYABUSA_ECU_R3.md`.
- **AFR-Zieltabelle** (nur Anzeige, keine Regelung): 14,2 im Leerlauf, 14,7 Teillast,
  12,8 bei Volllast.

## Erststart-Konfiguration

| Bereich | Einstellung | Grund |
|---|---|---|
| Einspritzung | Semi-Sequential, Paarung „1+3 & 2+4", divider 2 | phasenunabhängig; Paarung passt zur Kanalzuordnung oben |
| Zündung | **Wasted COP**, `IgInv` Going Low | phasenunabhängig, doppelte Spulenbelastung nur für die Inbetriebnahme |
| Fixed Timing | **Ein, 10°** | Trigger-Winkel ist unverifiziert; Zündung fest bis Blitzpistolen-Check |
| Trigger | Dual Wheel, 8 Zähne, Single tooth cam, Winkel **350° ATDC**, RISING/RISING, Filter Weak, Resync Ja, Skip 3, Cranking-Winkel 5° | siehe „Trigger" |
| Dwell | 1,6 ms Lauf, 2,5 ms Start, Limiter 4 ms, Spannungskurve 100 % ab 14 V | Denso-Stabspulen 0,8–1,2 Ω, gemessene Sättigung ≈ 2 ms bei 14 V |
| Begrenzer | weich 5500 (fest 10°), hart 6000, Fuel + Spark | Inbetriebnahme; Stock-Limit 10900 |
| Kraftstoffkorrekturen | Cranking 300/220/160/120 % bei −40/0/30/80 °C, ASE 30–10 %, WUE 160→100 %, IAT-Dichte 126→79 %, AE TPS 50 %/s, Multiplikator | Speeduino-übliche Startwerte |
| Düsen | Totzeit 1,0 ms, Duty-Limit 85 %, Prime 6/4/3/2 ms, Pumpe 3 s vor, Prime-Verzögerung 0,5 s | |
| MAP | Stock-IAP 18590-81A00 hinter 12k/20k: 10 kPa bei 0 V, 142 kPa bei Vollausschlag; `multiplyMAP` Aus; Baro aus MAP beim Einschalten | Kennlinie ≈ 25·V + 10 kPa ist aus den Suzuki-Bändern abgeleitet, am Fahrzeug prüfen |
| TPS | 53 / 208 ADC (1,1 V / 4,3 V) | **muss kalibriert werden** |
| Lambda | Wide Band, keine Regelung, 30 s Verzögerung | LC-2 Ausgang 0–3,3 V, Preset „Innovate LC-1/LC-2" |
| Aus | DFCO, Boost-Cut, Launch, Flat-Shift, Leerlaufregelung, Lüfter, Klopfen, CAN, Nitrous, VVT, WMI, Staging, 2. Tabellen, Logging | |

## Trigger

Das 1999er Rad hat **8 gleichmäßig verteilte Zähne ohne Lücke**, Sensor VR; der
Nockenwellensensor (VR, neben der Spule von Zylinder 1) liefert einen Puls je
Nockenwellenumdrehung. Speeduino: „Dual Wheel", Zahn 1 ist der erste Kurbelzahn nach dem
Cam-Puls, der Trigger-Winkel ist die Kurbelstellung in Grad **nach** OT Zylinder 1, bei der
Zahn 1 den Sensor passiert.

Es gibt keinen verifizierten Wert für dieses Rad. Die für die Hayabusa kursierenden Zahlen
(100/460, −100/260, 105) gelten für das 24-1-Rad ab 2002. Einzige Referenz mit 8+1 und
MAX9926 ist ein Speeduino-Forumsprojekt („Hayabusa Gen1", 2023): 350° mit RISING/RISING,
per Blitzpistole bestätigt; mit FALLING lag der Wert bei 160. Beide sind Startwerte,
Motor-zu-Motor-Streuung liegt bei bis zu 5°. Ein Fehler um einen Zahn (45°) bedeutet
Rückschlag oder kein Start.

## Vor dem ersten Start

1. **Firmware** mit den drei Korrekturen bauen und flashen. TunerStudio: Projekt
   `tune/Hayabusa-R3` öffnen, unter *Project Properties → Settings* muss „Hayabusa multi map
   switching = Enabled" stehen, COM-Port anpassen (`project.properties` steht auf COM1).
2. **Erster Verbindungsaufbau** (leerer SPI-Flash): TunerStudio meldet, dass Controller und
   Datei abweichen → **Datei auf den Controller schreiben** (nicht umgekehrt), *Burn*, danach
   ECU **aus- und einschalten**. Erst nach dem Neustart ist Board 57 aktiv (Watchdog,
   OUTEN, MC33810). Kontrolle: FI-Lampe geht nach 2 s aus, `pinLayout` zeigt „Gen1 Hayabusa
   ECU R3".
3. **Kalibrierungen** (liegen nicht im Tune, sondern nur im Steuergerät):
   - *Tools → Calibrate Thermistor Tables*, CLT und IAT: Bias-Widerstand **2490 Ω**
     (Pull-up gegen 3,3 V = ADC-Referenz, daher exakt). Punkte Stock-ECT: 20 °C 2450 Ω,
     50 °C 811 Ω, 80 °C 318 Ω. IAT: 20 °C 2,2–2,7 kΩ laut Suzuki, restliche Punkte messen
     (Eiswasser, kochendes Wasser) oder ECT-Kurve übernehmen. Danach müssen CLT und IAT
     Umgebungstemperatur zeigen. Ein CLT bei −40 °C bedeutet Kabelbruch oder fehlende
     Kalibrierung und würde 300 % Startanreicherung auslösen.
   - *Tools → Calibrate TPS*: geschlossen und Vollgas. Prüfen: 0 % im Leerlaufanschlag,
     linear bis 100 %. Ohne Kalibrierung läuft der Leerlauf auf der falschen Lastzeile.
   - *Tools → Calibrate AFR Table*: Preset „Innovate LC-1 / LC-2 Default". Voraussetzung:
     LC-2 Analogausgang 1 im LM Programmer auf **0,00 V = AFR 7,35 … 3,30 V = AFR 22,39**
     programmiert (der Eingang J2.38 endet bei 3,3 V). Kontrolle: Sonde in Luft ≥ 20 AFR.
     Heizerausgang J2.46 **offen lassen**, der LC-2 heizt selbst.
   - MAP: Zündung an, Motor aus → Anzeige muss dem Luftdruck entsprechen (95–102 kPa).
     Weicht sie ab, `mapMax` anpassen (Kennlinie ist abgeleitet, nicht Suzuki-Spezifikation).
   - Batteriespannung mit Multimeter vergleichen (nur mit korrigierter Firmware richtig).
4. **Kanalzuordnung prüfen** (*Tools → Test Output Hardware*): IGN3 muss die Spule von
   **Zylinder 4** klicken lassen, IGN4 die von Zylinder 3, INJ3 die Düse von Zylinder 4,
   INJ4 die von Zylinder 3. Kerzenstecker dabei mit gemasseten Kerzen.
5. **Trigger prüfen**, Kraftstoffpumpen-Sicherung gezogen oder Düsen abgesteckt:
   - *Tools → Tooth Logger / Composite Logger* beim Anlassen: 8 Zähne je Umdrehung, ein
     Cam-Puls je zwei Umdrehungen, Sync stabil, Sync Loss 0. Springt der Sync, Filter auf
     Off oder Kanten auf FALLING testen; die Anlasserdrehzahl muss gleichmäßig sein.
   - Fixed Timing auf **0°** stellen, Kerzen eingebaut, Blitzpistole an Zylinder 1, anlassen:
     die T-Marke im Schauloch des Anlasserdeckels muss stehen. Steht sie nicht, Trigger-Winkel
     ändern, bis sie steht (Kandidaten 350, dann 160; sonst in Schritten). Anschließend
     Fixed Timing zurück auf 10°, *Burn*.
6. **Sicherheit**: Feuerlöscher, Notaus, LC-2 angeschlossen und angezeigt, Kühlung
   angeschlossen. Kippschalter-Polarität beachten: geht die FI-Lampe nicht aus oder feuern
   die Spulen im Hardware-Test nicht, meldet die Firmware „umgekippt"
   (`HAYABUSA_TIPOVER_INVERTED` in `platformio.ini`).

## Erster Start und danach

1. Kraftstoff an, anlassen. AFR im Leerlauf 12–14 anstreben; die Zellen 0–4 % TPS unter
   2000 rpm (Wert 40) direkt nach Gehör/AFR nachziehen. Nicht lange im fetten Leerlauf
   stehen lassen. Leerlaufdrehzahl mechanisch an der Anschlagschraube (Stock 1150 ± 100).
2. Zündzeitpunkt bei laufendem Motor mit Blitzpistole gegen die feste Vorgabe von 10°
   prüfen (Abstand zur T-Marke). Stimmt er bei zwei Drehzahlen, sind Winkel und Flanke
   richtig. Dann **Fixed Timing aus, Burn**. Solange Fixed Timing an ist, wirken keine
   Zündkorrekturen und kein weicher Begrenzer; nur der harte Schnitt bei 6000 schützt.
3. Warmlauf: WUE gegen AFR prüfen (kalt 12,5–13, warm 14,7 Teillast).
4. **Sequential**: Einspritzung auf Sequential, Zündung auf Sequential, Burn. Startet oder
   läuft der Motor dann nicht mehr, liegt die Nockenwellenphase um 360° verkehrt: Trigger-
   Winkel um 360 verschieben (350 → −10). Danach halbiert sich die Spulenbelastung.
5. Begrenzer schrittweise anheben, nur mit LC-2 unter Last: oberhalb ca. 9000 rpm reicht
   die Düsenkapazität bei 257 cc/min knapp (Duty > 90 %), das Duty-Limit von 85 % macht das
   Gemisch dort mager. Vor Volllastfahrten Duty-Limit auf 90–95 % und AFR bei Volllast
   12,5–13,0 nachweisen; Stock-Begrenzer 10900.
6. Offene Punkte für später: Klopfsensor (TPIC8101, Modus Analog), DFCO, Lambda-Regelung,
   Sensor-Modul über CAN, Gangsensor-Schwellen (`HAYABUSA_GEAR_THRESHOLDS`),
   MAP-basierte Zweittabelle für Leerlauf und Schub, Lüfter über J2.29.

## Bekannte Abweichungen zur übrigen Dokumentation

`docs/TUNING.md`, `docs/INSTALLATION.md`, `docs/HARDWARE.md` und `docs/SOFTWARE.md`
beschreiben noch den Dropbear-Aufbau (Rev 1) mit anderen Pins, Trigger- und
Kalibrierwerten (2,7 kΩ / 5 V, 36-1, mapMax 100, Dwell 4 ms, reqFuel 13,2). Für die Rev 3
gilt dieses README zusammen mit `speeduino/HAYABUSA_ECU_R3.md`.

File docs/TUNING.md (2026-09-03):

# Tuning-Guide

TunerStudio-Konfiguration der Gen1 Hayabusa ECU Rev 3 (Speeduino-Fork, Board 57) für die
Hayabusa 1999. Quelle der Wahrheit für alle Zahlen ist `tune/Hayabusa-R3/tools/gen_tune.py`;
dieses Dokument erklärt die Zusammenhänge und die Reihenfolge der Abstimmung.

> **Stand:** September 2026. Erststart-Tune erzeugt, Motor damit noch nicht gelaufen.
> Trigger-Winkel, TPS und Kalibrierungen sind am Fahrzeug zu bestimmen.

## 1. Fahrzeug- und Setup-Daten

| Komponente | Zustand |
|---|---|
| Modell | Suzuki Hayabusa Gen 1, **Baujahr 1999** (Modell X, 16-bit-Serien-ECU, frühes Kurbelrad) |
| Hubraum | 1299 cc, Reihen-4, Zündfolge 1-2-4-3, Zylinder 1 links |
| Verdichtung | **12 : 1** (Wössner-Kolben; Serie 11 : 1) |
| Airbox | Serie, zentrale Drosselklappen, Sekundärklappen passiv |
| Einspritzdüsen | Serie 15710-24F00, Keihin, hochohmig; **Annahme 257 cc/min bei 3 bar** (24,5 lb/h), Flowbench-Berichte 240–280 |
| Kraftstoffdruck | 3,0 bar Differenzdruck (Serienregler mit Unterdruckreferenz bei 1999/2000) |
| Zündung | Serien-Stabspulen Denso 33410-24F00, 0,8–1,2 Ω, ohne Igniter, direkt an den ISL9V5036 |
| Kurbeltrigger | Serie: **8 Zähne gleichmäßig, keine Lücke**, VR |
| Nockentrigger | Serie: ein Stift auf der Einlassnocke, VR |
| MAP | Serien-IAP 18590-81A00 an J2.58 |
| TPS, CLT, IAT | Serie |
| Lambda | Innovate LC-2 + Bosch LSU 4.9, Analogausgang 1 auf 0–3,3 V an J2.38 |
| Klopfsensor | TPIC8101 auf der Platine, Sensor Bosch 0 261 231 173 noch nicht verbaut |
| Leerlauf | mechanisch (Wachselement, Anschlagschraube), keine ECU-Regelung |
| Lüfter | Serien-Thermoschalter |
| Turbo | nicht verbaut |
| TunerStudio | MS Ultra |

## 2. Projekt

```text
File → Open Project → tune/Hayabusa-R3
Project Properties → Settings → Hayabusa multi map switching = Enabled
Communications → Connect
```

Die Projekt-INI `tune/Hayabusa-R3/projectCfg/mainController.ini` ist eine Kopie von
`speeduino/reference/speeduino.ini` des passenden Fork-Stands und muss byteidentisch
bleiben. Niemals eine offizielle Speeduino-INI einsetzen: Board 57, Seiten 16–21 und die
INI-Korrekturen fehlen dort.

Änderungen am Tune über den Generator:

```bash
python3 tune/Hayabusa-R3/tools/gen_tune.py
```

Was TunerStudio live verändert (Kalibrierungen, VE Analyze), wird in der .msq gespeichert
und beim nächsten Generatorlauf überschrieben, wenn es nicht in `gen_tune.py` nachgezogen
wird. Restore-Points vor jeder Änderung.

## 3. Engine Constants

| Parameter | Erststart | danach |
|---|---|---|
| `pinLayout` | Gen1 Hayabusa ECU R3 | |
| `nCylinders` / `engineType` / `twoStroke` | 4 / Even fire / Four-stroke | |
| `nInjectors` / `injType` | 4 / Port | |
| `injLayout` | **Semi-Sequential**, Paarung „1+3 & 2+4", `divider` 2 | Sequential, `divider` 4 |
| `algorithm` / `ignAlgorithm` | TPS (Alpha-N) für beides | |
| `multiplyMAP` | Off | offen; die Stock-Map ist nicht auf MAP/Baro normiert |
| `mapSample` | Cycle Average | |
| `stoich` | 14,7 | |
| `reqFuel` | **8,3 ms** (1299 cc, 4 Zyl., 14,7, 257 cc/min) | bei bestätigtem Düsendurchsatz neu rechnen |
| `injOpen` | 1,0 ms bei 14 V | messen |
| `dutyLim` | 85 % | 90–95 % nach Volllastnachweis |

`reqFuel` ist der Kraftstoff je Zylinder und Arbeitsspiel bei VE 100 %. Die Firmware
halbiert ihn selbst für Semi-Sequential; beim Wechsel auf Sequential bleibt der Wert.

## 4. Trigger

| Parameter | Wert |
|---|---|
| `TrigPattern` | Dual Wheel |
| `numTeeth` / `missingTeeth` | 8 / 0 |
| `trigPatternSec` | Single tooth cam |
| `TrigEdge` / `TrigEdgeSec` | RISING / RISING (MAX9926) |
| `TrigSpeed` | Crank Speed |
| `TrigAng` | **350° ATDC**, unverifiziert |
| `TrigFilter` / `useResync` / `SkipCycles` | Weak / Ja / 3 |
| `CrankAng` | 5° |
| `fixAngEnable` / `FixAng` | **On / 10°** bis der Trigger-Winkel bestätigt ist |

Zahn 1 ist der erste Kurbelzahn nach dem Nockenpuls; `TrigAng` ist seine Position in Grad
nach OT Zylinder 1. Für das 8-Zahn-Rad gibt es keinen belegten Wert; die kursierenden
Zahlen (100/460, −100/260) gehören zum 24-1-Rad ab 2002. Ein Speeduino-Projekt mit 8+1 und
MAX9926 lief mit 350 (RISING) bzw. 160 (FALLING). Ein Zahn Fehler sind 45°.

Verfahren: siehe [INSTALLATION.md](INSTALLATION.md), Abschnitt „Trigger". Kurz: Tooth
Logger ohne Kraftstoff, dann Fixed Timing 0° und Blitzpistole auf die T-Marke, Winkel
korrigieren, Fixed Timing 10° zum Start. Läuft der Motor später in Sequential nicht, Winkel
um 360 verschieben (350 → −10).

## 5. Zündung

| Parameter | Erststart | danach |
|---|---|---|
| `sparkMode` | **Wasted COP** | Sequential, sobald die Nockenphase stimmt |
| `IgInv` | Going Low | |
| `dwellrun` / `dwellcrank` | 1,6 / 2,5 ms | |
| `useDwellLim` / `dwellLim` | On / 4 ms | |
| `sparkDur` | 1,0 ms | |
| Dwell-Spannungskurve | 240/200/150/130/100/100 % bei 6/8/10/12/14/20 V | oberhalb 14 V flach als Schutz gegen falsche Spannungsanzeige |
| `perToothIgn` / `dwellErrCorrect` | Ja / On | |

Die Serienspulen sättigen bei etwa 2 ms und 14 V; der Serien-ECU-Wert am Begrenzer liegt
bei 1,5 ms. Wasted COP verdoppelt die Spulenbelastung, deshalb 1,6 ms und so bald wie
möglich Sequential.

Zündkennfeld: Stock-Map `IGN_org` aus `tune/setup/maps.ods`, bilinear auf die 16×16-Achsen
interpoliert, **−3° bei Last ≥ 25 % und ≥ 2000 rpm** wegen 12:1 ohne Klopfsensor. Leerlauf
9° bei 800 rpm (Serie: 4° bei 1200 rpm). Das Blatt `ING` in der ODS ist nicht die
Serienzündung und wird nicht verwendet.

## 6. Kraftstoff

### 6.1 VE-Tabelle

Stock-TPS-Kennfeld (23 × 42) bilinear auf 16 × 16 interpoliert und mit 120/205 skaliert
(Maximum 120 %). Zellen 0–4 % TPS unter 2000 rpm auf 40 gesetzt: das Serien-Steuergerät
nutzt dort die IAP-Map (Umschaltpunkt ≈ 11 % TPS), die TPS-Werte sind dort nicht
aussagekräftig. Erwartung im Leerlauf ≈ 2,7 ms je Einspritzung, eher fett; mit dem LC-2
auf 13,5–14 ziehen.

Achsen: Drehzahl 800/1200/1600/2000/2400/2800/3400/4000/4800/5600/6400/7200/8000/9200/
10400/12000, Last 0/2/4/6/8/10/13/16/20/25/30/40/50/60/75/100 % TPS.

### 6.2 Korrekturen

| Funktion | Startwerte |
|---|---|
| Cranking | 300/220/160/120 % bei −40/0/30/80 °C, `crankRPM` 500, `tpsflood` 90 % |
| Prime | 6/4/3/2 ms bei −40/0/30/80 °C, 0,5 s nach Pumpenstart, Pumpe 3 s |
| ASE | 30/25/20/10 % für 8/6/5/3 s bei −40/0/20/60 °C |
| WUE | 160/152/145/138/130/123/116/108/102/100 % bei −40 … 80 °C |
| IAT-Dichte | 126 → 79 % von −40 bis 100 °C (ideales Gas) |
| Düsen-Spannungskurve | 250/200/150/120/100/100 % bei 6/8/10/12/14/20 V |
| AE | TPS-Modus, Schwelle 50 %/s, Mindeständerung 3 %, 250 ms, Multiplikator 10/25/45/70 % bei 0/60/150/400 %/s, kalt 120 % bis 60 °C |
| DFCO | Aus, erst nach Lambda-Regelung: 2500 rpm, Hysterese 250, TPS < 2 %, CLT > 60 °C, 1 s |
| Baro-Korrektur | Aus |

### 6.3 Volllast

Mit 257 cc/min liegt die Düsenauslastung oberhalb 9000 rpm über 90 %; das Duty-Limit von
85 % magert dort ab. Vor Volllastfahrten: AFR 12,5–13,0 unter Last nachweisen, Duty-Limit
anheben, Sequential (spart eine Totzeit je Arbeitsspiel), Begrenzer erst dann über 9500.

## 7. Sensoren

| Sensor | Einstellung |
|---|---|
| TPS | `tpsMin` 53 / `tpsMax` 208 als Startwert, **am Fahrzeug kalibrieren** (1,1 V / 4,3 V hinter 12 k/20 k) |
| MAP | `mapMin` 10 / `mapMax` 142 kPa (Serien-IAP ≈ 25·V + 10 kPa, Vollausschlag 5,28 V). Kennlinie ist abgeleitet; bei Zündung an muss der Umgebungsdruck stehen |
| Baro | aus MAP beim Einschalten (`useExtBaro` No) |
| CLT / IAT | Thermistor-Kalibrierung mit Bias **2490 Ω**: 20 °C 2450 Ω, 50 °C 811 Ω, 80 °C 318 Ω. Pull-up hängt an 3,3 V wie die ADC-Referenz, daher exakt |
| Batterie | Firmware skaliert für den 47 k/10 k-Teiler; `batVoltCorrect` 0 |
| Lambda | LC-2 Analogausgang 1: **0,00 V = AFR 7,35 … 3,30 V = AFR 22,39** (Innovate-Standard-AFR, nur Endspannung 5 → 3,3 V). TunerStudio *Calibrate AFR Table* Preset „Innovate LC-1 / LC-2 Default". `egoType` Wide Band, `egoAlgorithm` No correction, `ego_sdelay` 30 s. Analogausgang 2 isolieren, LC-2-Analogmasse an J2.54, Heizerausgang J2.46 offen |

Einbau der Sonde: Edelstahl-Stutzen M18×1,5 im Akrapovič-Mittelrohr, 10–2 Uhr, ≥ 45 cm
hinter dem Auslass, vor dem Dämpfer (im Sammler kollidiert die Sonde mit dem Motor).
Alternative bei Turbo: Downpipe hinter dem Lader. CAN statt analog (AEM X-Series 0x180,
rusEFI-WBO, `canWBO`) bleibt möglich.

Lambda-Regelung, sobald Sonde und VE grob passen: `egoAlgorithm` Simple, KP/KI/KD 80/60/50,
`egoLimit` 15 %, `egoRPM` 1500, `egoTPSMax` 70 %, `egoTemp` 60 °C.

## 8. Leerlauf

Kein IAC-Ventil: `iacAlgorithm` None, Leerlaufdrehzahl an der Anschlagschraube (Serie
1150 ± 100). Bei unruhigem warmen Leerlauf: Zellen 0–4 % TPS bei 800–1600 rpm, dann
`idleAdvEnabled` Added mit kleiner Kurve. Der Schrittmotortreiber auf der Platine bleibt
ungenutzt.

## 9. Begrenzer und Schutz

| Parameter | Erststart | Ziel |
|---|---|---|
| `SoftRevLim` / Modus | 5500, fest 10° für 1,5 s | 10500 |
| `hardRevLim` / `hardCutType` | 6000 / Full | 10900 (Serie), `engineProtectType` Both |
| `boostCutEnabled` | **Off** (Saugmotor); `boostLimit` 200 kPa | |
| AFR-Schutz | Aus | nach vertrauenswürdigem LC-2: Tabellenmodus, +1,5 AFR, > 4000 rpm, > 80 % TPS |
| Öldruck-Schutz | Aus | mit Sensor-Modul |

Solange Fixed Timing an ist, wirken weder Zündkorrekturen noch der weiche Begrenzer.

## 10. Klopfregelung

Der TPIC8101 wird von der Firmware konfiguriert (6,37 kHz, Verstärkung Index 14, 200 µs);
Fenster am Zündfunken. Tune: `knock_mode` **Off** bis der Sensor verbaut ist, dann
**Analog** (Pin wird ignoriert), Schwelle am Motor mit Klopfaufzeichnung bestimmen, Rücknahme
3° je Ereignis, maximal 8°, oberhalb 9000 rpm aus. Bis dahin bleibt die Zündung 3° unter
Serie.

## 11. AFR-Zieltabelle

16 × 16, nur Referenz für VE Analyze (`incorporateAFR` No): 14,2 im Leerlauf, 14,7 bei
15–30 % TPS, 13,8 bei 50 %, 12,8 bei 100 %.

## 12. Ablauf der Abstimmung

1. Statischer Test, Kalibrierungen, Hardware-Test (Kanalzuordnung!).
2. Trigger ohne Kraftstoff: Tooth Logger, Blitzpistole, `TrigAng`.
3. Erststart mit Fixed Timing 10°, Wasted COP, Semi-Sequential; Leerlaufzellen mit LC-2
   nachziehen; Zündzeitpunkt bei zwei Drehzahlen prüfen; Fixed Timing aus, Burn.
4. Sequential für Einspritzung und Zündung; startet der Motor nicht, `TrigAng` ± 360.
5. Warmlauf: WUE gegen AFR.
6. Teillast: VE Analyze Live, Ziel `afrTable`, Filter CLT > 75 °C, Änderung ≤ 5 % je
   Durchlauf, manuell freigeben.
7. Volllast nur auf dem Prüfstand, Begrenzer schrittweise, Düsenauslastung beobachten.
8. Danach: Lambda-Regelung, DFCO, Klopfsensor, Sensor-Modul, Kennfeldsätze 2–4 mit
   eigenen Inhalten (bisher Kopien von Satz 1), MAP-basierte Zweittabelle für Leerlauf
   und Schub.

Datenlogging: TunerStudio-Log über USB (On-board-Logging im Tune aus). Pflichtkanäle RPM,
TPS, MAP, CLT, IAT, Battery, Sync Loss, AFR, VE, Advance, PW, Dwell. Logs nicht ins
Repository.

## 13. Dateien und Backups

```
tune/Hayabusa-R3/
├── CurrentTune.msq               generiert
├── README.md                     Herkunft, Checkliste, Verfahren
├── projectCfg/mainController.ini Kopie der Fork-INI, nicht ersetzen
├── projectCfg/project.properties
└── tools/                        gen_tune.py, stockmaps.py, iniparse.py, msqinfo.py, dumptables.py
tune/setup/maps.ods               Serienkennfelder (VE_org, IGN_org)
```

Restore-Points vor jeder Änderung (`File → Save As`), TunerStudio legt `restorePoints/`
selbst an. Änderungen nach erfolgreichem Test in den Generator übernehmen und committen.

## 14. Störungssuche

| Symptom | Prüfen |
|---|---|
| Keine Drehzahl | Tooth Logger, Flanke, Sensorwiderstand, Kabelführung Kurbelsensor |
| Sync springt | Anlasserdrehzahl, Filter Off, Nockenleitung getrennt von Spule 1 |
| Funke, kein Sprit | Pumpenlauf 3 s, `tpsflood`, Düsen im Hardware-Test |
| Zwei Zylinder, Fehlzündungen in den Auspuff | Kanalzuordnung IGN3 = Zylinder 4, Firmware-Stand |
| Sequential startet nicht | `TrigAng` ± 360 |
| Zu fett im Leerlauf | Zellen 0–4 % TPS senken, TPS-Kalibrierung |
| Mager bei hoher Drehzahl | Düsenauslastung, `dutyLim`, `reqFuel` gegen echten Düsendurchsatz |
| −40 °C / 130 °C | Kabel oder fehlende Thermistor-Kalibrierung |
| Batterie 18 V | Firmware ohne Board-57-Skalierung |

## 15. Offene Punkte

- [ ] Trigger-Winkel und Flanke am Motor bestätigen.
- [ ] TPS, Thermistoren, AFR kalibrieren.
- [ ] Düsendurchsatz belegen (Teilenummer ablesen, Flowbench), `reqFuel` nachrechnen.
- [ ] IAP-Kennlinie gegen Umgebungsdruck prüfen.
- [ ] Kippschalter-Polarität, Gangsensor-Schwellen.
- [x] LC-2 + LSU 4.9 beschafft (2026-09-01, `docs/BESTELLUNG.ods`); Einbau offen.
- [ ] Klopfsensor Bosch 0 261 231 173 verbauen, Schwelle kalibrieren.
- [ ] Sequential, Begrenzer anheben, DFCO, Lambda-Regelung.

## 16. Quellen

- Speeduino-Wiki: https://wiki.speeduino.com · Forum: https://speeduino.com/forum
- TunerStudio: http://tunerstudio.com
- Fork: https://github.com/HasiKe/speeduino, Branch `Hayabusa/ECU-R3`
- Projekt: [HARDWARE.md](HARDWARE.md), [INSTALLATION.md](INSTALLATION.md),
  [SOFTWARE.md](SOFTWARE.md), `tune/Hayabusa-R3/README.md`

---

**Version:** 4.0
**Stand:** September 2026

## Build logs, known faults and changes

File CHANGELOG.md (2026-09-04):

# Changelog

Alle wichtigen Änderungen an diesem Projekt werden in dieser Datei dokumentiert.

Das Format basiert auf [Keep a Changelog](https://keepachangelog.com/de/1.0.0/).
Die Abschnitte folgen der tatsächlichen Repository-Historie (erster Commit
2024-11-06). Vergeben ist bisher nur das Tag **v0.1** (2025-10-01); die übrigen
Überschriften sind Zeitabschnitte, keine Releases.

## [Unreleased]

### Hinzugefügt
- TunerStudio-Projekt `tune/Hayabusa-R3` für die Rev 3 (Board 57), generiert aus den Serienkennfeldern in `tune/setup/maps.ods` (`tools/gen_tune.py`), Erststart-Konfiguration mit Checkliste im README
- Firmware-Fork: Kanalzuordnung nach Zündfolge 1-2-4-3 am Serienstecker, Batteriespannungs-Skalierung für den 47k/10k-Teiler, TunerStudio-INI korrigiert (ignTrim auf Seite 13, Load-Achsen der Kennfeldsätze 3/4, boostTable3/4)
- Exhaust-Mic als Submodul `hardware/exhaust-mic` (HasiKe/Exhaust-Mic)
- Innovate LC-2 mit LSU 4.9 als Lambda-Lösung festgelegt und in `docs/BESTELLUNG.ods` aufgenommen

### Geändert
- Dokumentation (HARDWARE, SOFTWARE, INSTALLATION, TUNING, PROJECT_STRUCTURE) komplett auf die Rev 3 und das neue Tune-Projekt umgeschrieben; die Dropbear-Beschreibungen der Rev 1 entfallen
- Sensor-Modul-Firmware in den Speeduino-Fork verschoben (`speeduino/sensor-module/`)

### Entfernt
- Alte TunerStudio-Projekte (`tune/Busa`, `tune/Hayabusa-R1`) samt Dashboards und Datenlogs
- Verwaistes `smc_test`-Projekt aus `hardware/ECU`
- Repository auf die Elektronik beschränkt: `hardware/` enthält nur noch `ECU/` und `exhaust-mic/`; Zwischenstände des Layouts, extern geladene Werkzeuge und Datenlogs bleiben lokal

### Offen
- Erster Motorlauf mit dem Tune `Hayabusa-R3` (Trigger-Winkel, Kalibrierungen, Kanalzuordnung am Fahrzeug bestätigen)
- Sensor-Modul am Fahrzeug erproben, CAN-Eingänge im Tune aktivieren
- Klopfsensor Bosch 0 261 231 173 verbauen und Schwelle kalibrieren
- Fertigung der Rev-3-Platinen und des Exhaust-Mic

## 2026-08 bis 2026-09

### Hinzugefügt
- Exhaust-Mic: Spezifikation, Schaltpläne (Hauptplatine und Mikrofonkopf), gerenderte PDFs, Layout
- Sensor-Modul-Firmware (STM32G474)

### Geändert
- ECU-Hardware auf den Stand der Revision 3.0 gebracht (Schaltplan und Layout beider Platinen)

## 2026-04 bis 2026-05

### Hinzugefügt
- Explosionszeichnungen der Suzuki-Ersatzteilkataloge, Drehmomenttabelle, ARP- und Wössner-Einbauanleitungen
- Berechnungen zur Auslegung (`docs/Berechnungen.ods`)

### Geändert
- Verzeichnisstruktur: `Hardware/` umbenannt zu `hardware/` (Kleinschreibung)
- Speeduino-Submodul von `speeduino/speeduino` auf den Fork `HasiKe/speeduino` gewechselt, Pfad des `teensy.pretty`-Submoduls korrigiert
- Dokumentation überarbeitet (Dropbear v2, Klopfsensor)

## [v0.1] - 2025-10-01

Erstes Tag. Stand: ECU-Layout der Revision 1 gefertigt, Abstimmung mit dem
TunerStudio-Projekt `Hayabusa-R1`.

### Hinzugefügt
- Serienkennfelder aus dem Original-Steuergerät (`tune/setup/maps.ods`)
- Pinout-Blatt des Serien-Steuergeräts

### Geändert
- ECU-Layout in Schritten v0.1 bis v0.3, überarbeitete 5-V-Versorgung
- KiCad-Projekt auf Version 9 gehoben

## 2024-11 bis 2025-05

### Hinzugefügt
- Projektstart: KiCad-Projekt des Steuergeräts, zweilagige Platine
- Submodule `speeduino` und `hardware/ECU/lib/teensy.pretty`
- Eigene Symbol- und Footprint-Bibliotheken für die Automotive-Bausteine
- Erstes TunerStudio-Projekt

---

## Kategorien

- **Hinzugefügt**: Neue Features
- **Geändert**: Änderungen an bestehenden Features
- **Entfernt**: Entfernte Inhalte
- **Behoben**: Bugfixes
- **Offen**: Noch nicht erledigt

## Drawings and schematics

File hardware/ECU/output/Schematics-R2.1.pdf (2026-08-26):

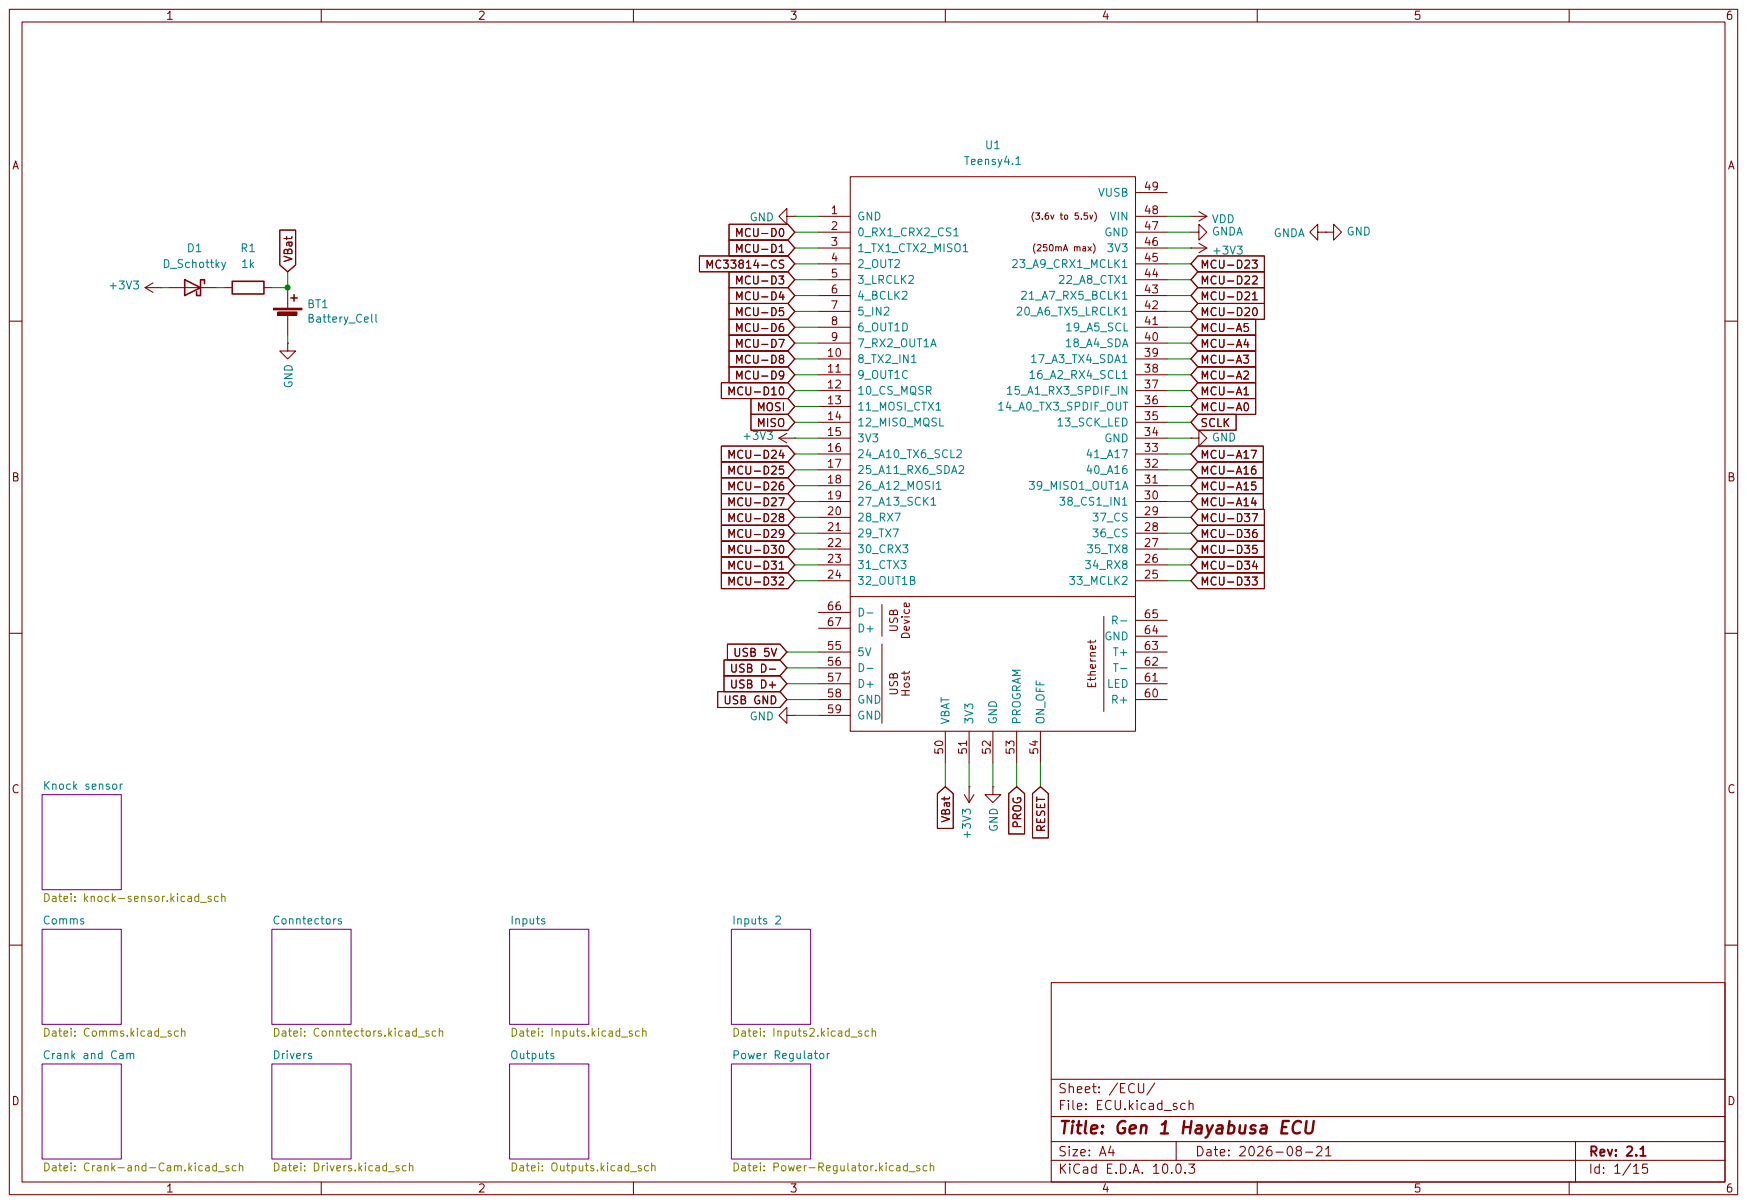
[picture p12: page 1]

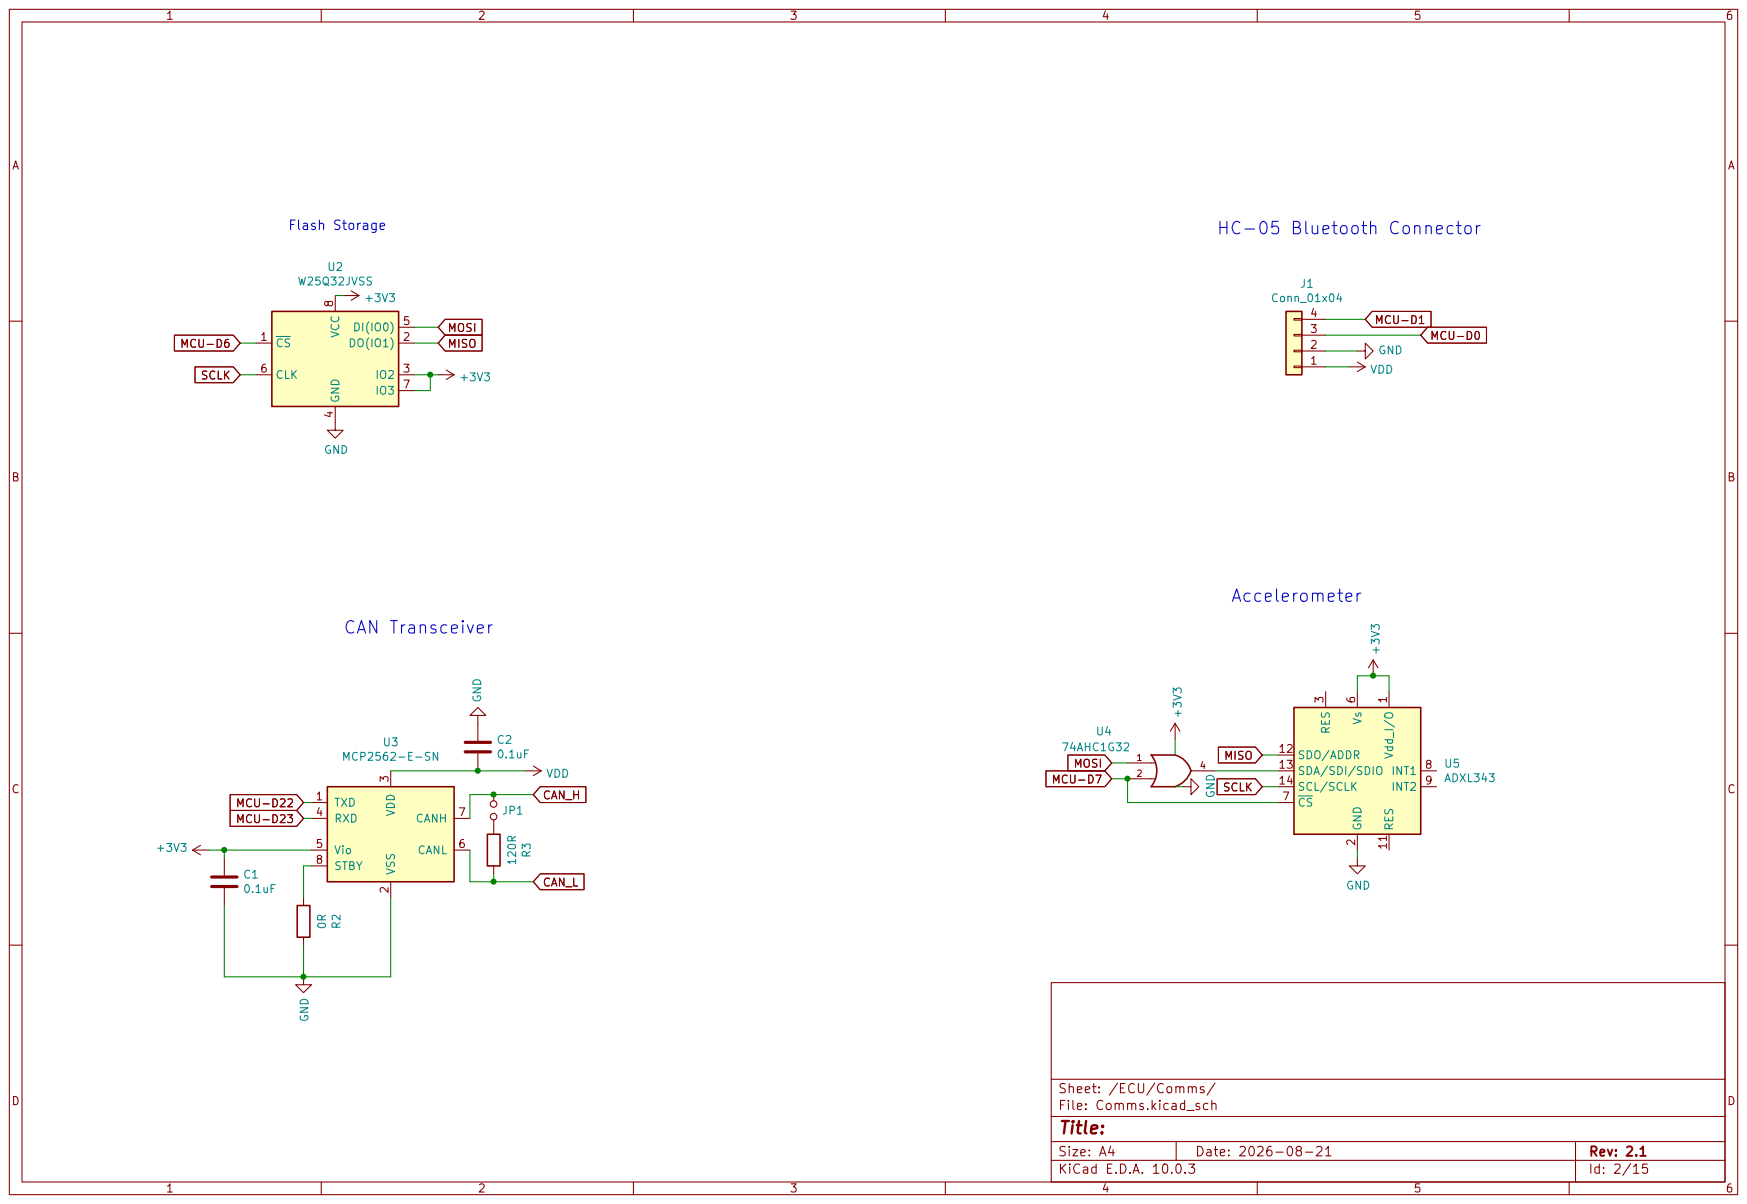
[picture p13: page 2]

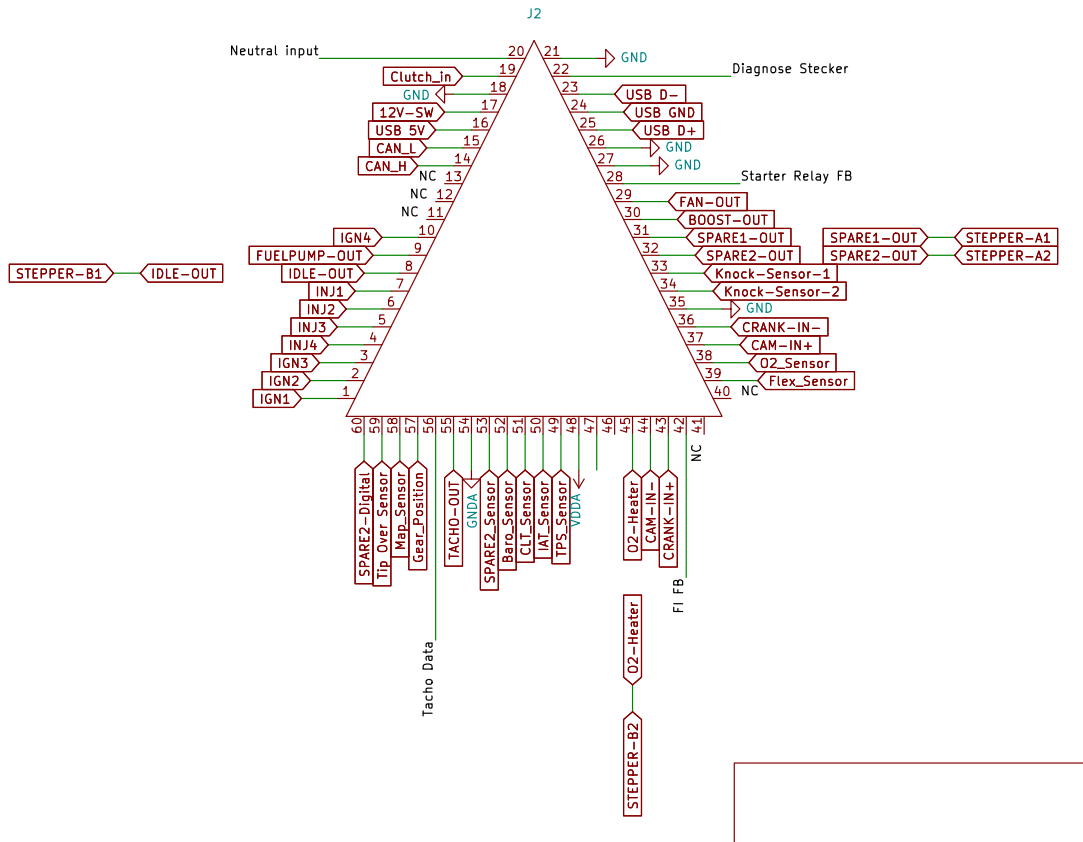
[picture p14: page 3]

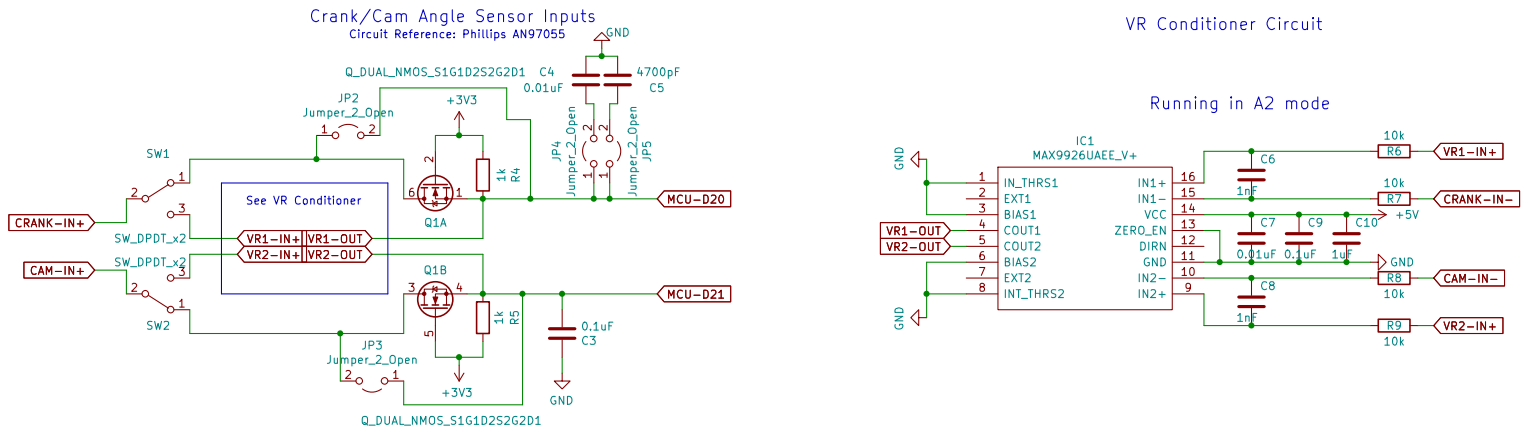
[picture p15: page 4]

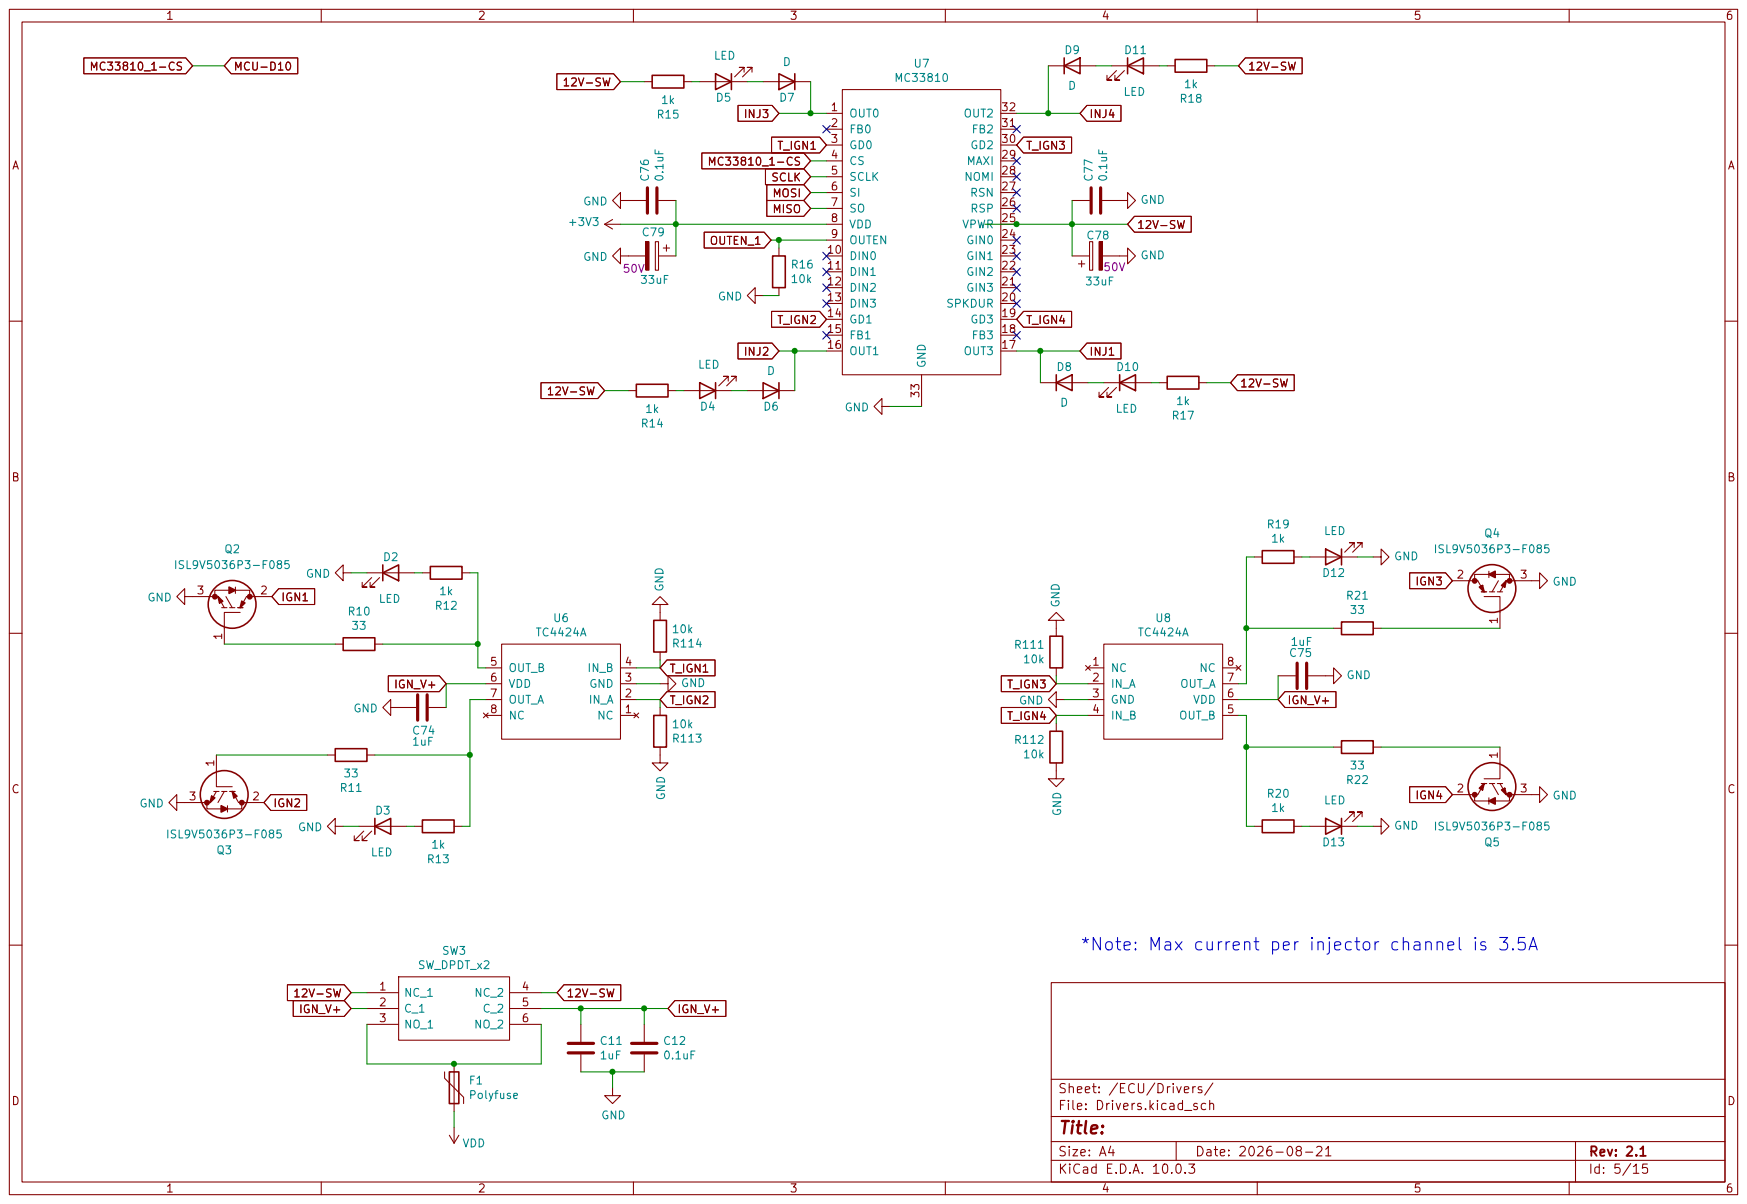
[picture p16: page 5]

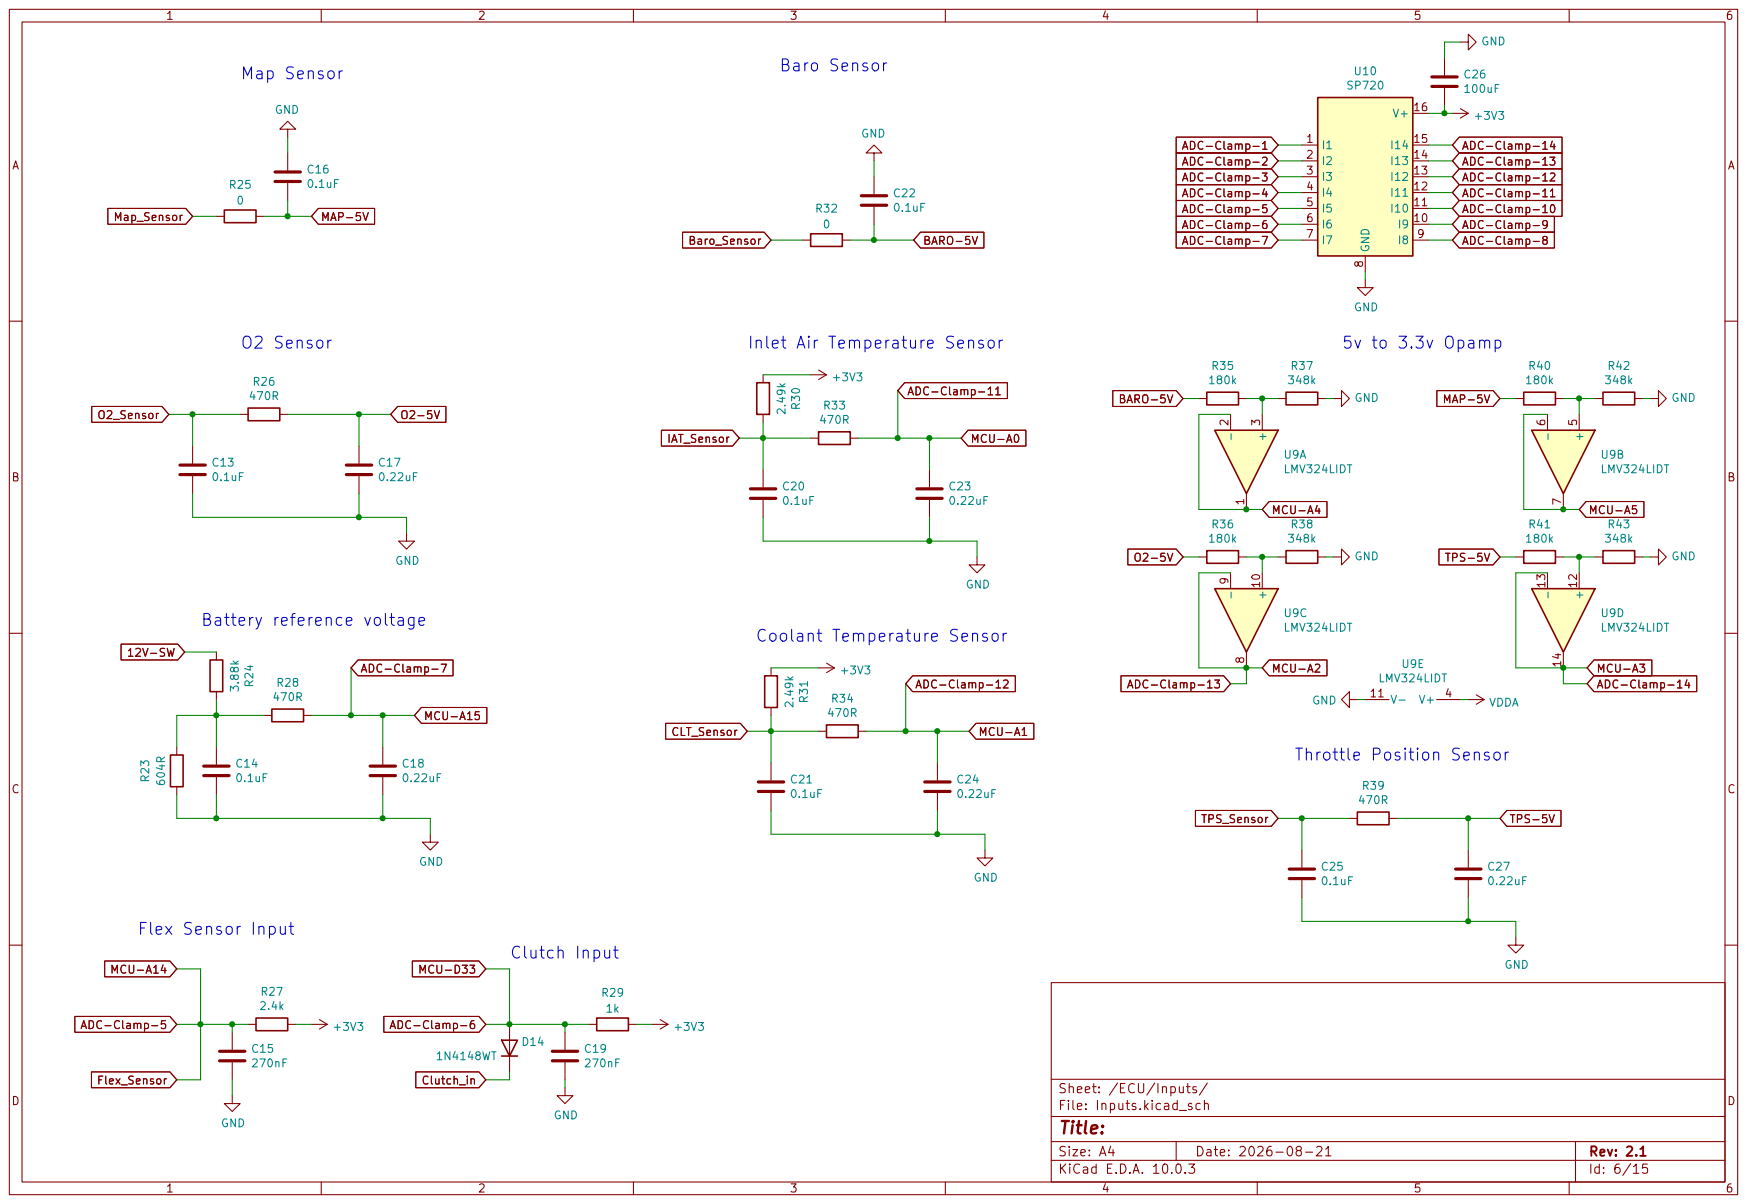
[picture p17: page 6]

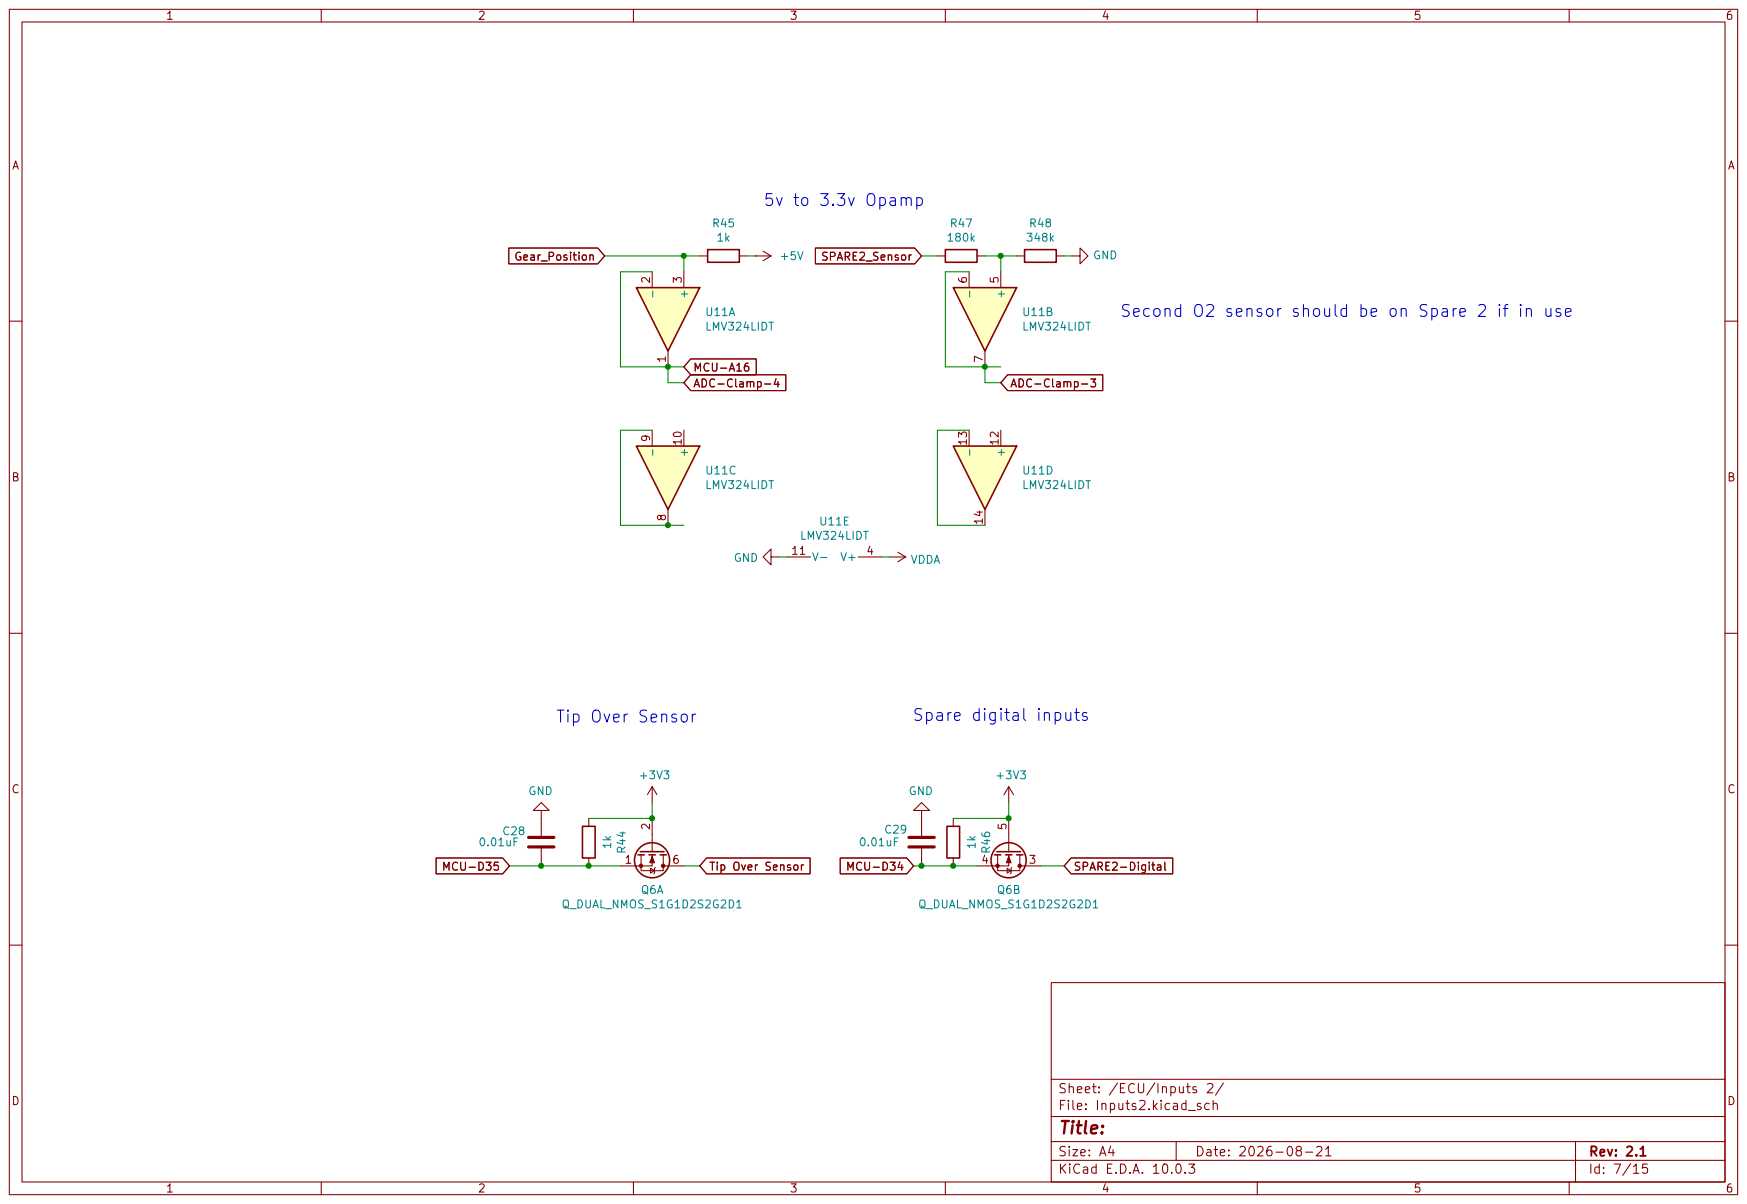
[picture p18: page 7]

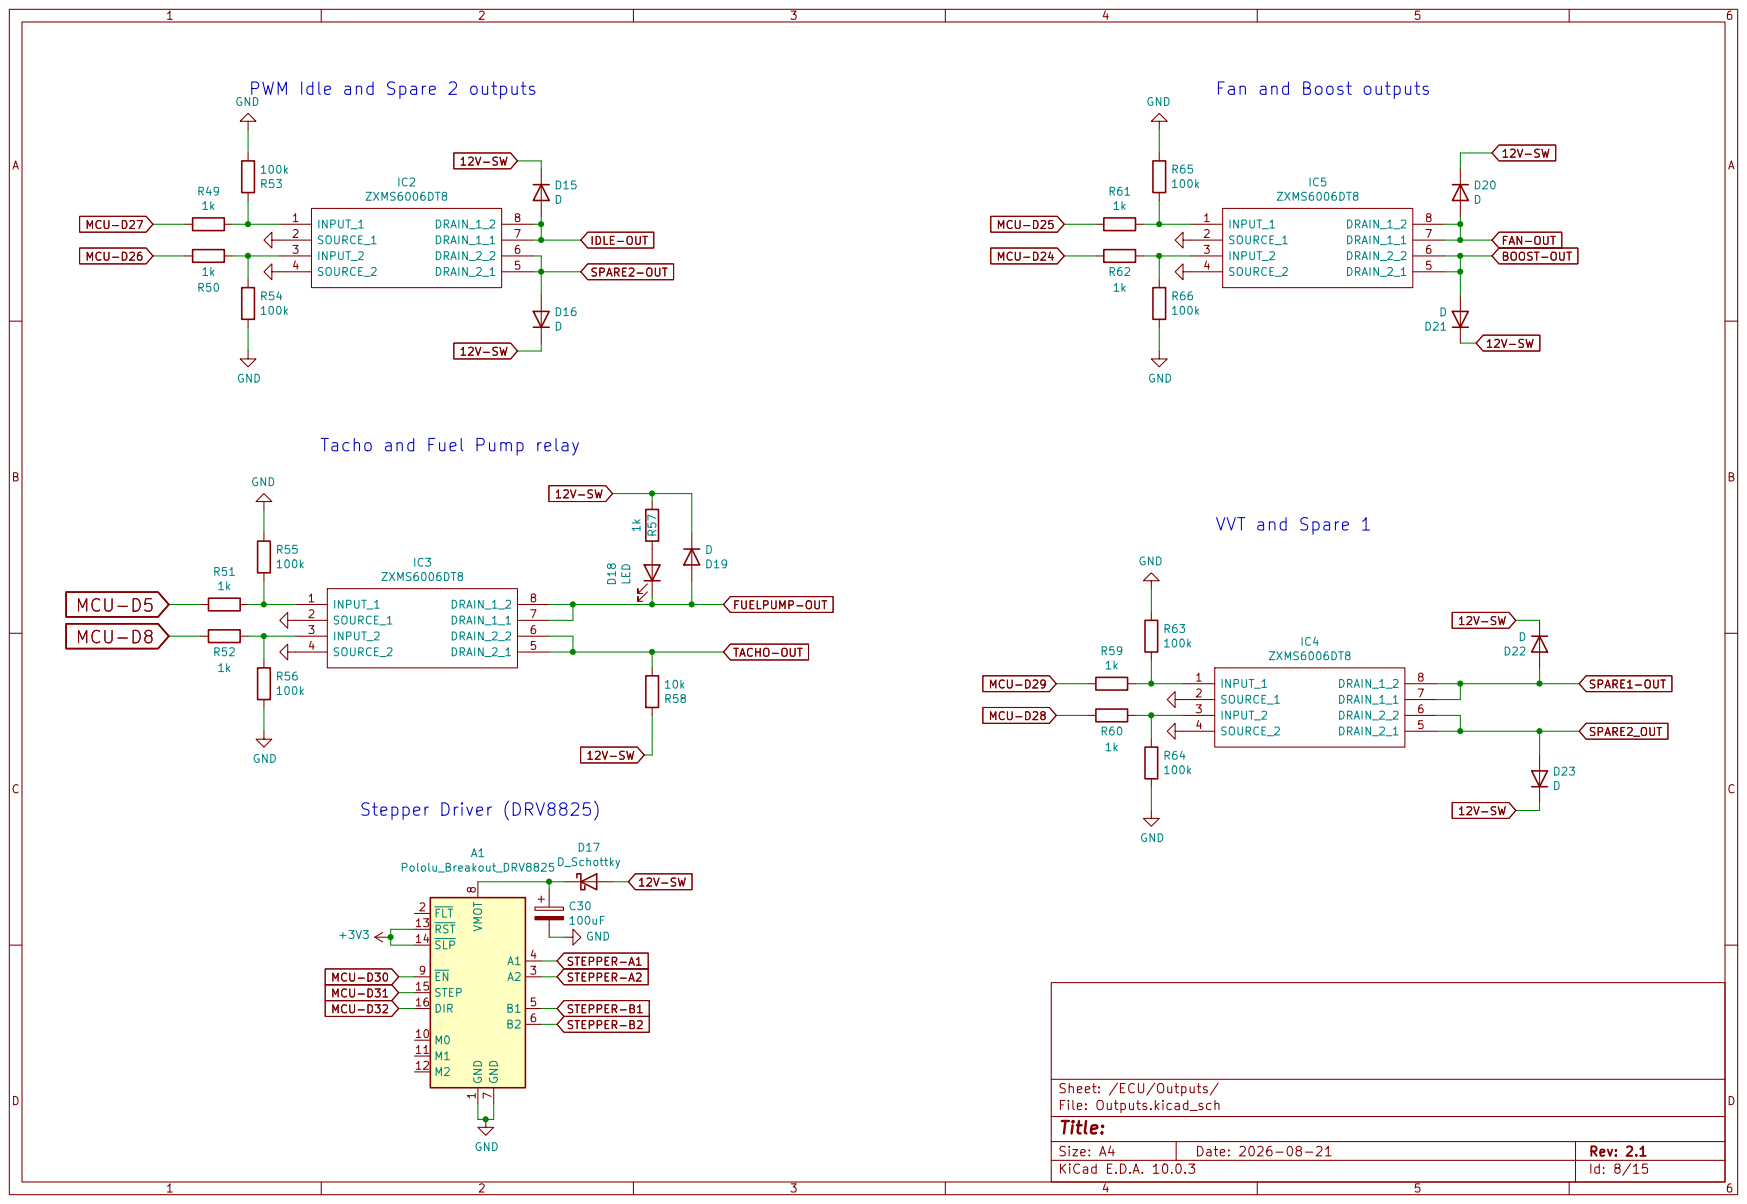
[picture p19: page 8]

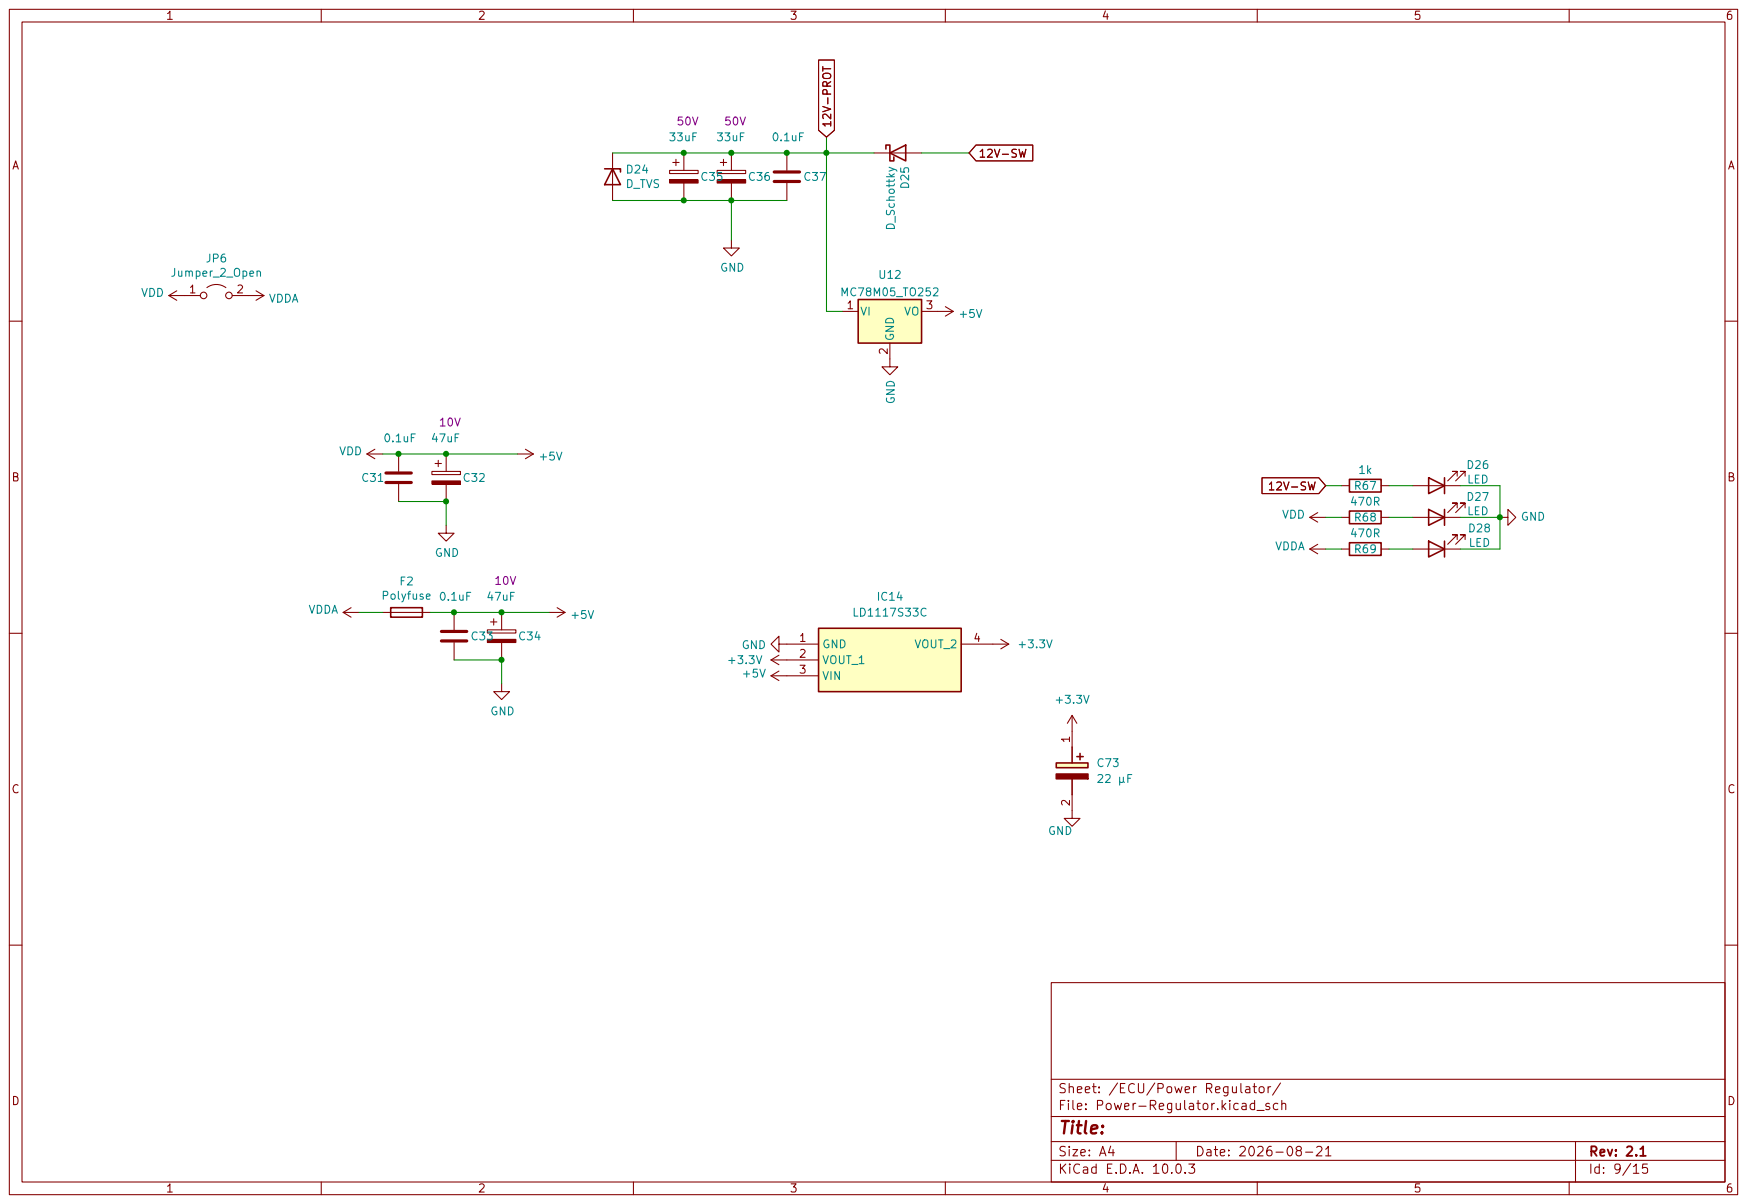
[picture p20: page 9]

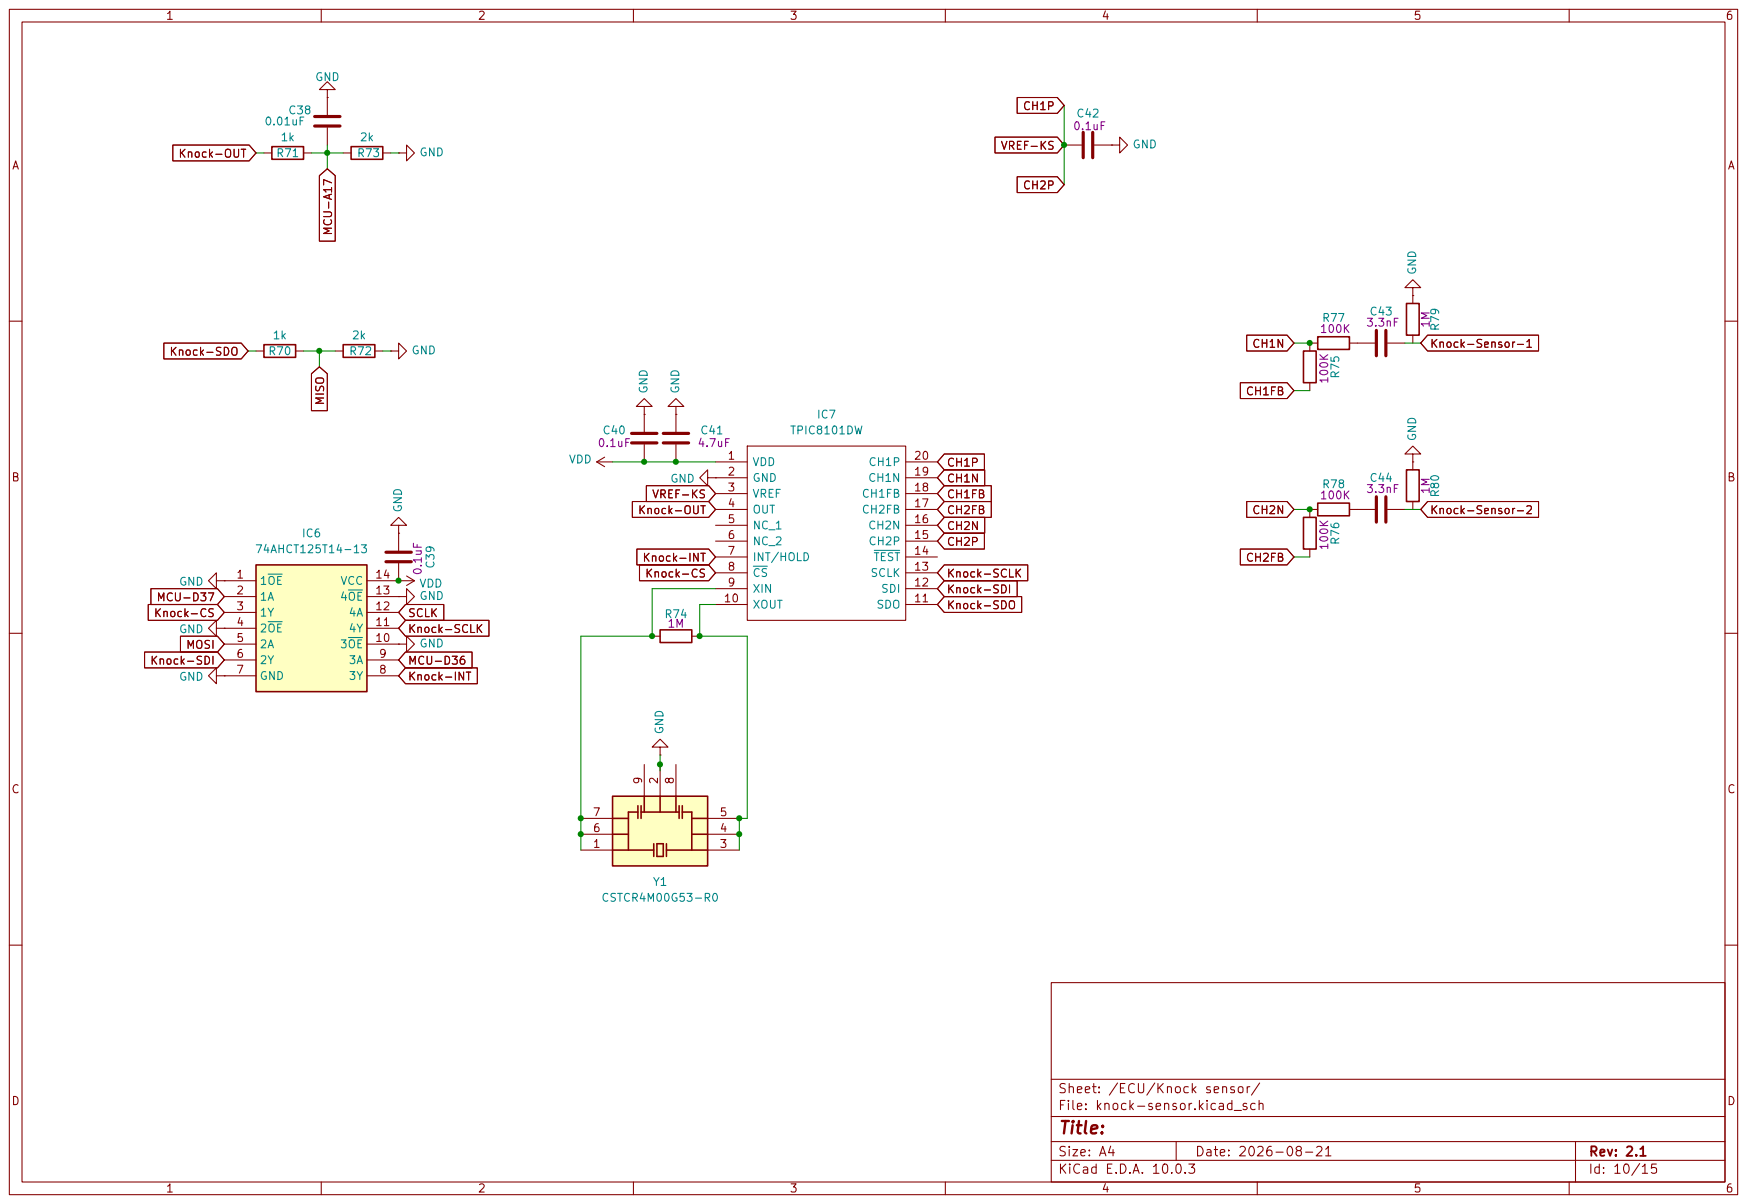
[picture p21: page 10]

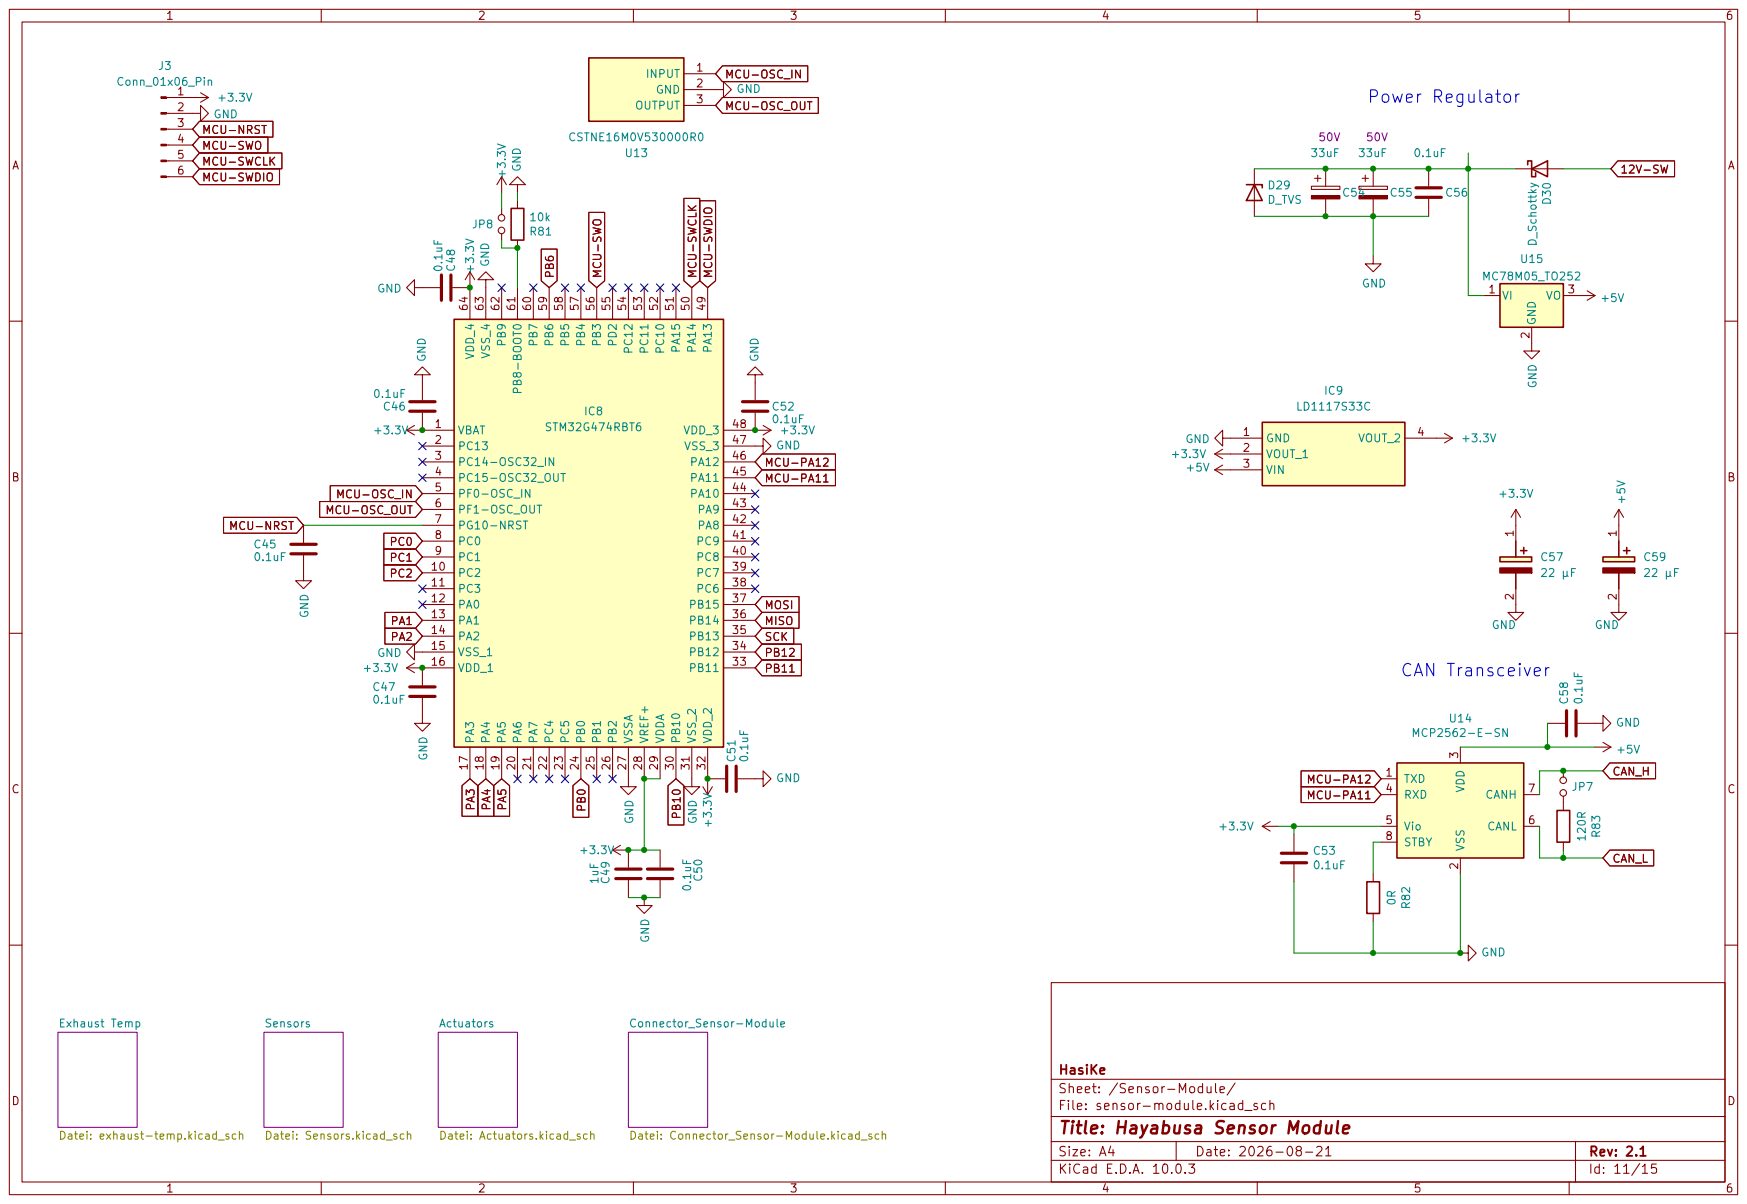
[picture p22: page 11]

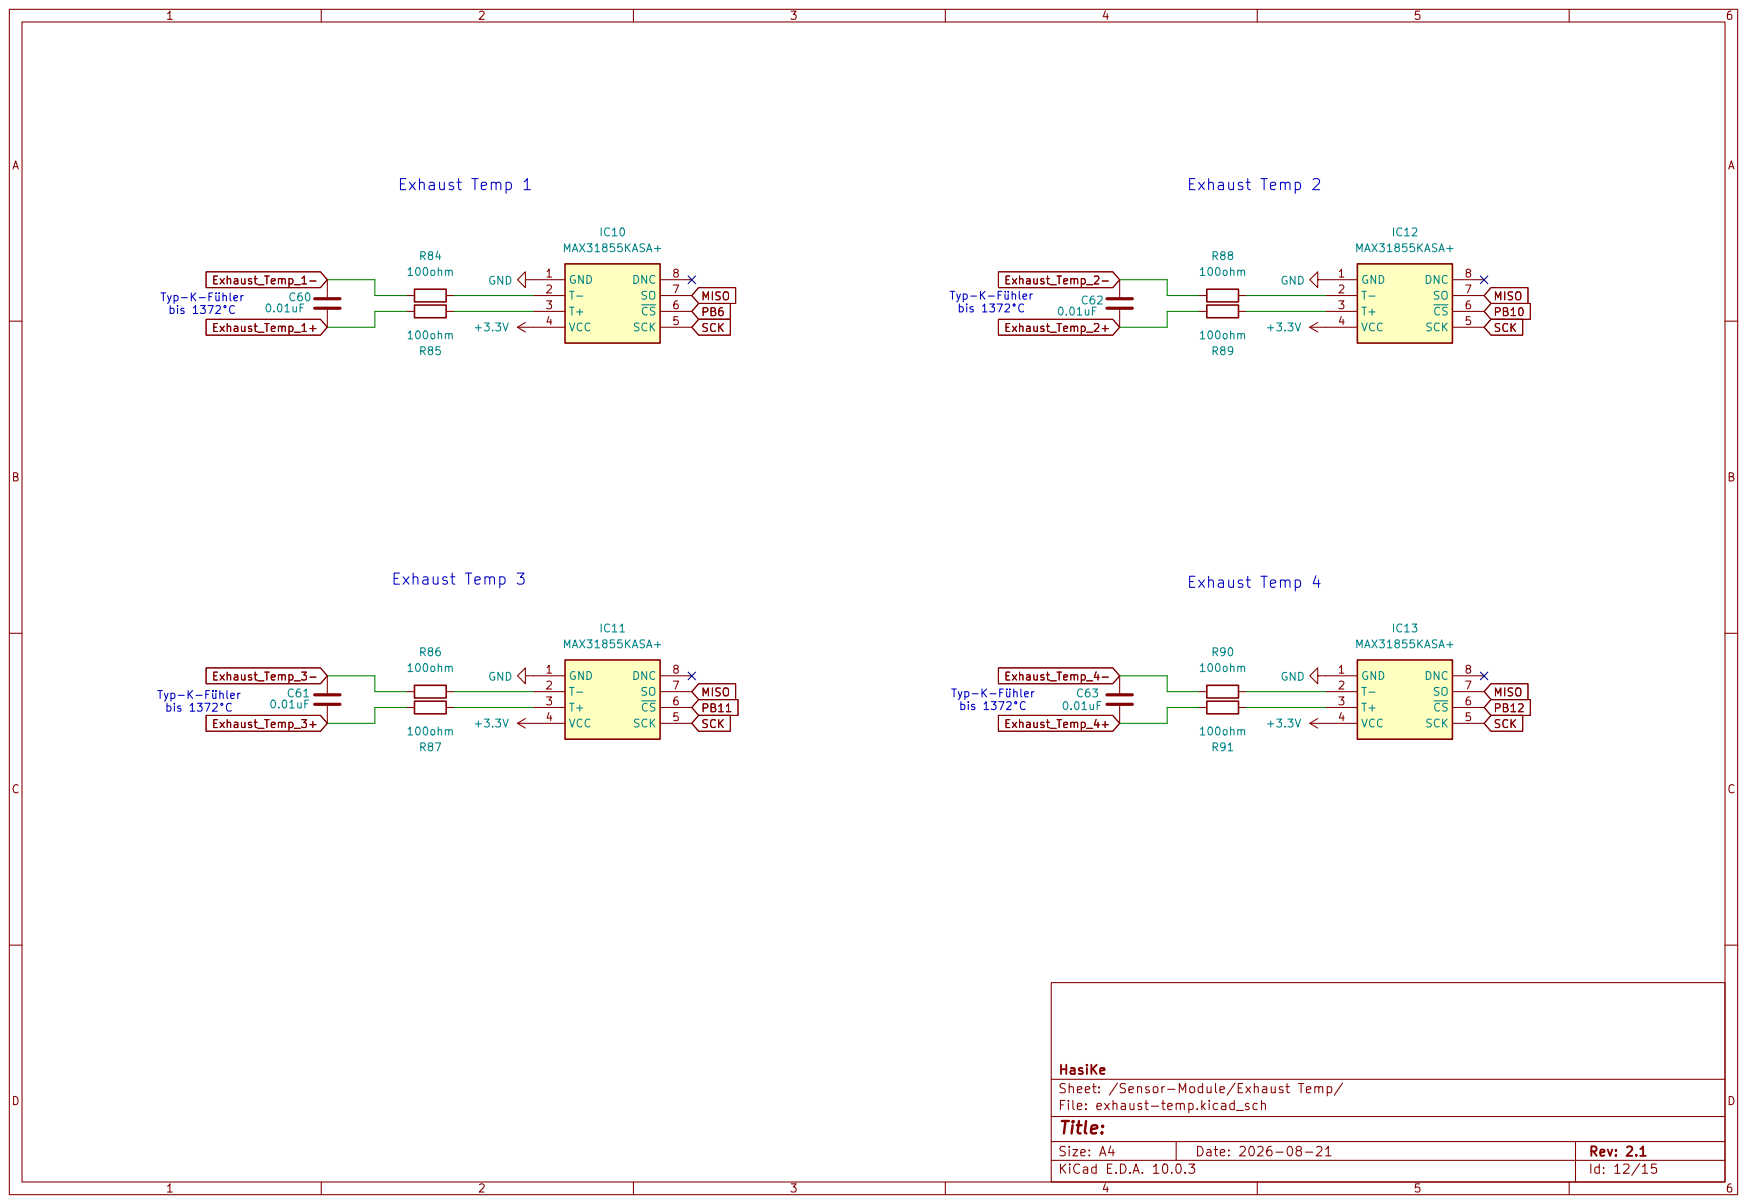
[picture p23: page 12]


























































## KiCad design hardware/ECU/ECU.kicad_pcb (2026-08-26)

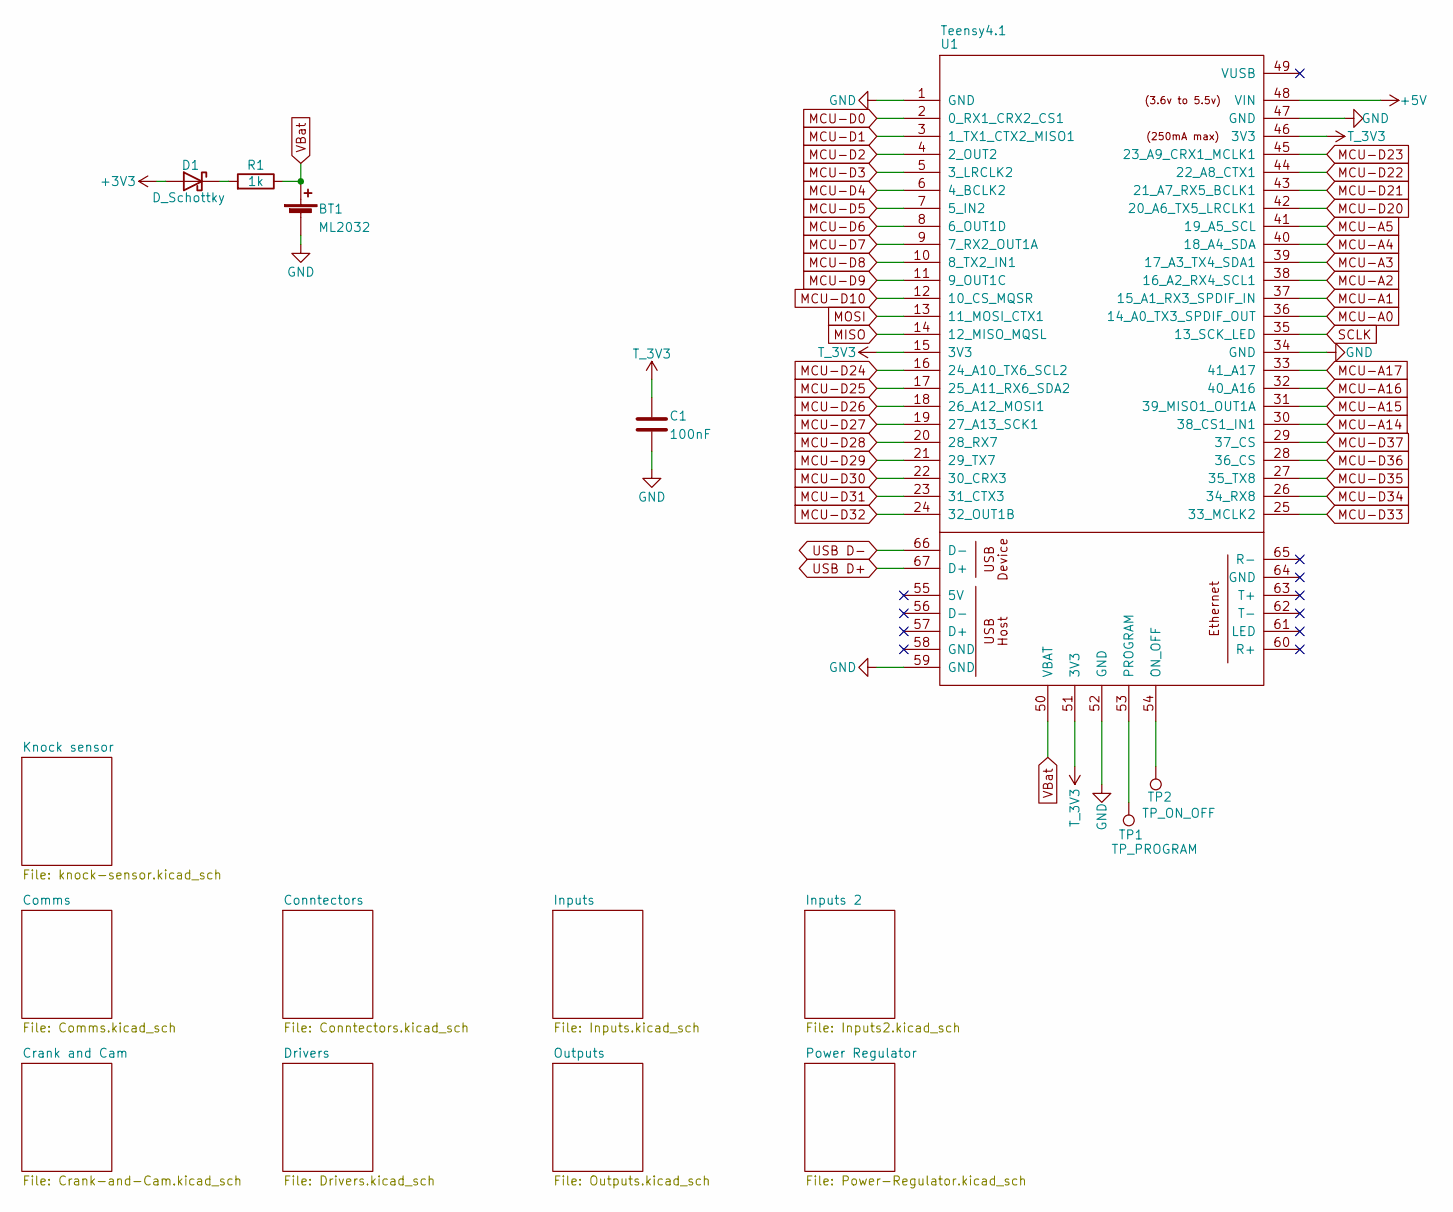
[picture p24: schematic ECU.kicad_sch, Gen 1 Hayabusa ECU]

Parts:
BT1: ML2032; BatteryHolder_Keystone_3034_1x20mm; Manufacturer_Part_Number 3034; Digikey Part Number 36-3034-ND
C1: 100nF; C_0805_2012Metric; Manufacturer_Part_Number CC0805KRX7R9BB104; Digikey Part Number 311-1140-1-ND
D1: D_Schottky; D_PowerDI-123; Manufacturer_Part_Number DFLS240-7; Digikey Part Number DFLS240-7DICT-ND
R1: 1k; R_0805_2012Metric; Manufacturer_Part_Number RC0805FR-071KL; Digikey Part Number 311-1.00KCRCT-ND
TP1: TP_PROGRAM; TestPoint_Pad_D1.5mm
TP2: TP_ON_OFF; TestPoint_Pad_D1.5mm
U1: Teensy4.1; Teensy41; Manufacturer_Part_Number DEV-16771; Digikey Part Number 1568-16771-ND

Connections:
+3V3: D1.2 (A); also elsewhere on the board
+5V: U1.48 (VIN); also elsewhere on the board
GND: BT1.2 (-), C1.2, U1.1 (GND), U1.34 (GND), U1.47 (GND), U1.52 (GND), U1.59 (GND); also elsewhere on the board
MC33810_1-CS: U1.12 (10_CS_MQSR); also elsewhere on the board
MCU-A0: U1.36 (14_A0_TX3_SPDIF_OUT); also elsewhere on the board
MCU-A1: U1.37 (15_A1_RX3_SPDIF_IN); also elsewhere on the board
MCU-A2: U1.38 (16_A2_RX4_SCL1); also elsewhere on the board
MCU-A3: U1.39 (17_A3_TX4_SDA1); also elsewhere on the board
MCU-A4: U1.40 (18_A4_SDA); also elsewhere on the board
MCU-A5: U1.41 (19_A5_SCL); also elsewhere on the board
MCU-A14: U1.30 (38_CS1_IN1); also elsewhere on the board
MCU-A15: U1.31 (39_MISO1_OUT1A); also elsewhere on the board
MCU-A16: U1.32 (40_A16); also elsewhere on the board
MCU-A17: U1.33 (41_A17); also elsewhere on the board
MCU-D0: U1.2 (0_RX1_CRX2_CS1); also elsewhere on the board
MCU-D1: U1.3 (1_TX1_CTX2_MISO1); also elsewhere on the board
MCU-D2: U1.4 (2_OUT2); also elsewhere on the board
MCU-D3: U1.5 (3_LRCLK2); also elsewhere on the board
MCU-D4: U1.6 (4_BCLK2); also elsewhere on the board
MCU-D5: U1.7 (5_IN2); also elsewhere on the board
MCU-D6: U1.8 (6_OUT1D); also elsewhere on the board
MCU-D7: U1.9 (7_RX2_OUT1A); also elsewhere on the board
MCU-D8: U1.10 (8_TX2_IN1); also elsewhere on the board
MCU-D9: U1.11 (9_OUT1C); also elsewhere on the board
MCU-D20: U1.42 (20_A6_TX5_LRCLK1); also elsewhere on the board
MCU-D21: U1.43 (21_A7_RX5_BCLK1); also elsewhere on the board
MCU-D22: U1.44 (22_A8_CTX1); also elsewhere on the board
MCU-D23: U1.45 (23_A9_CRX1_MCLK1); also elsewhere on the board
MCU-D24: U1.16 (24_A10_TX6_SCL2); also elsewhere on the board
MCU-D25: U1.17 (25_A11_RX6_SDA2); also elsewhere on the board
MCU-D26: U1.18 (26_A12_MOSI1); also elsewhere on the board
MCU-D27: U1.19 (27_A13_SCK1); also elsewhere on the board
MCU-D28: U1.20 (28_RX7); also elsewhere on the board
MCU-D29: U1.21 (29_TX7); also elsewhere on the board
MCU-D30: U1.22 (30_CRX3); also elsewhere on the board
MCU-D31: U1.23 (31_CTX3); also elsewhere on the board
MCU-D32: U1.24 (32_OUT1B); also elsewhere on the board
MCU-D33: U1.25 (33_MCLK2); also elsewhere on the board
MCU-D34: U1.26 (34_RX8); also elsewhere on the board
MCU-D35: U1.27 (35_TX8); also elsewhere on the board
MCU-D36: U1.28 (36_CS); also elsewhere on the board
MCU-D37: U1.29 (37_CS); also elsewhere on the board
MISO: U1.14 (12_MISO_MQSL); also elsewhere on the board
MOSI: U1.13 (11_MOSI_CTX1); also elsewhere on the board
unnamed: D1.1 (K), R1.2
unnamed: TP2.1 (1_1), U1.54 (ON_OFF)
unnamed: TP1.1 (1_1), U1.53 (PROGRAM)
SCLK: U1.35 (13_SCK_LED); also elsewhere on the board
T_3V3: C1.1, U1.15 (3V3), U1.46 (3V3), U1.51 (3V3)
USB D+: U1.67 (D+); also elsewhere on the board
USB D-: U1.66 (D-); also elsewhere on the board
VBat: BT1.1 (+), R1.1, U1.50 (VBAT)

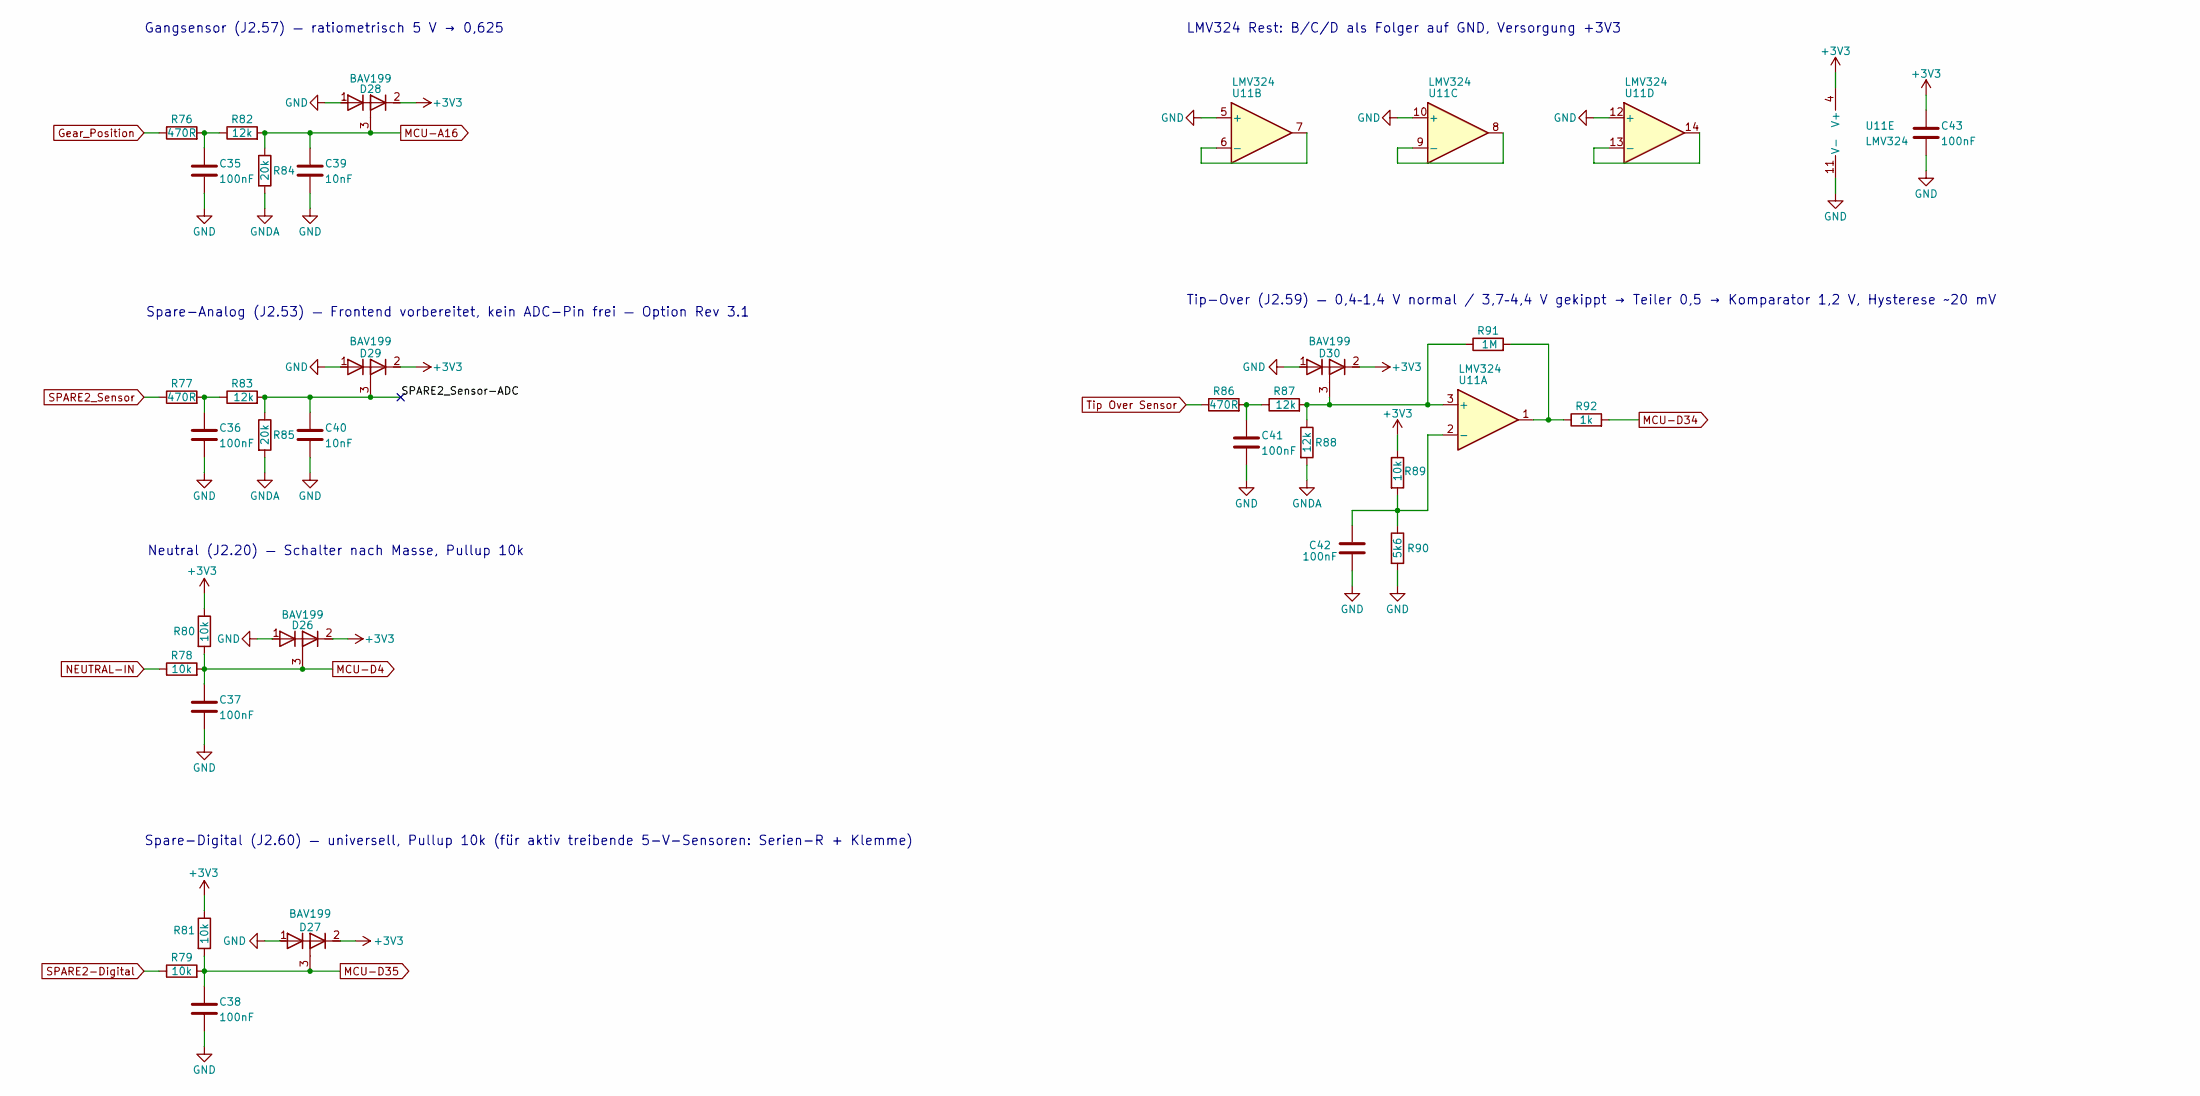
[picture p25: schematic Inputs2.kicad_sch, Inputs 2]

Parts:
C35, C36, C37, C38, C41, C42, C43: 100nF; C_0805_2012Metric; Manufacturer_Part_Number CC0805KRX7R9BB104; Digikey Part Number 311-1140-1-ND
C39, C40: 10nF; C_0805_2012Metric; Manufacturer_Part_Number CC0805KRX7R9BB103; Digikey Part Number 311-1136-1-ND
D26, D27, D28, D29, D30: BAV199; SOT-23; Manufacturer_Part_Number BAV199LT1G; Digikey Part Number BAV199LT1GOSCT-ND
R76, R77, R86: 470R; R_0805_2012Metric; Manufacturer_Part_Number RC0805FR-07470RL; Digikey Part Number 311-470CRCT-ND
R78, R79, R80, R81, R89: 10k; R_0805_2012Metric; Manufacturer_Part_Number RC0805FR-0710KL; Digikey Part Number 311-10.0KCRCT-ND
R82, R83, R87, R88: 12k; R_0805_2012Metric; Manufacturer_Part_Number RC0805FR-0712KL; Digikey Part Number 311-12.0KCRCT-ND
R84, R85: 20k; R_0805_2012Metric; Manufacturer_Part_Number RC0805FR-0720KL; Digikey Part Number 311-20.0KCRCT-ND
R90: 5k6; R_0805_2012Metric; Manufacturer_Part_Number RC0805FR-075K6L; Digikey Part Number 311-5.60KCRCT-ND
R91: 1M; R_0805_2012Metric; Manufacturer_Part_Number RC0805FR-071ML; Digikey Part Number 311-1.00MCRCT-ND
R92: 1k; R_0805_2012Metric; Manufacturer_Part_Number RC0805FR-071KL; Digikey Part Number 311-1.00KCRCT-ND
U11: LMV324; SOIC-14_3.9x8.7mm_P1.27mm; Manufacturer_Part_Number LMV324IDR; Digikey Part Number 296-9569-1-ND

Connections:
+3V3: C43.1, D26.2 (K2), D27.2 (K2), D28.2 (K2), D29.2 (K2), D30.2 (K2), R80.1, R81.1, R89.1, U11.4 (V+); also elsewhere on the board
/Inputs 2/SPARE2_Sensor-ADC: C40.1, D29.3 (K1A2), R83.2, R85.1
GND: C35.2, C36.2, C37.2, C38.2, C39.2, C40.2, C41.2, C42.2, C43.2, D26.1 (A1), D27.1 (A1), D28.1 (A1), D29.1 (A1), D30.1 (A1), R90.2, U11.5 (+), U11.10 (+), U11.11 (V-), U11.12 (+); also elsewhere on the board
GNDA: R84.2, R85.2, R88.2; also elsewhere on the board
Gear_Position: R76.1; also elsewhere on the board
MCU-A16: C39.1, D28.3 (K1A2), R82.2, R84.1; also elsewhere on the board
MCU-D4: C37.1, D26.3 (K1A2), R78.2, R80.2; also elsewhere on the board
MCU-D34: R92.2; also elsewhere on the board
MCU-D35: C38.1, D27.3 (K1A2), R79.2, R81.2; also elsewhere on the board
NEUTRAL-IN: R78.1; also elsewhere on the board
unnamed: C35.1, R76.2, R82.1
unnamed: C36.1, R77.2, R83.1
unnamed: C41.1, R86.2, R87.1
unnamed: D30.3 (K1A2), R87.2, R88.1, R91.1, U11.3 (+)
unnamed: R91.2, R92.1, U11.1
unnamed: C42.1, R89.2, R90.1, U11.2 (-)
unnamed: U11.6 (-), U11.7
unnamed: U11.8, U11.9 (-)
unnamed: U11.13 (-), U11.14
SPARE2-Digital: R79.1; also elsewhere on the board
SPARE2_Sensor: R77.1; also elsewhere on the board
Tip Over Sensor: R86.1; also elsewhere on the board

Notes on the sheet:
Spare-Digital (J2.60) — universell, Pullup 10k (für aktiv treibende 5-V-Sensoren: Serien-R + Klemme)
Spare-Analog (J2.53) — Frontend vorbereitet, kein ADC-Pin frei — Option Rev 3.1
Tip-Over (J2.59) — 0,4–1,4 V normal / 3,7–4,4 V gekippt → Teiler 0,5 → Komparator 1,2 V, Hysterese ~20 mV
LMV324 Rest: B/C/D als Folger auf GND, Versorgung +3V3
Gangsensor (J2.57) — ratiometrisch 5 V → 0,625
Neutral (J2.20) — Schalter nach Masse, Pullup 10k

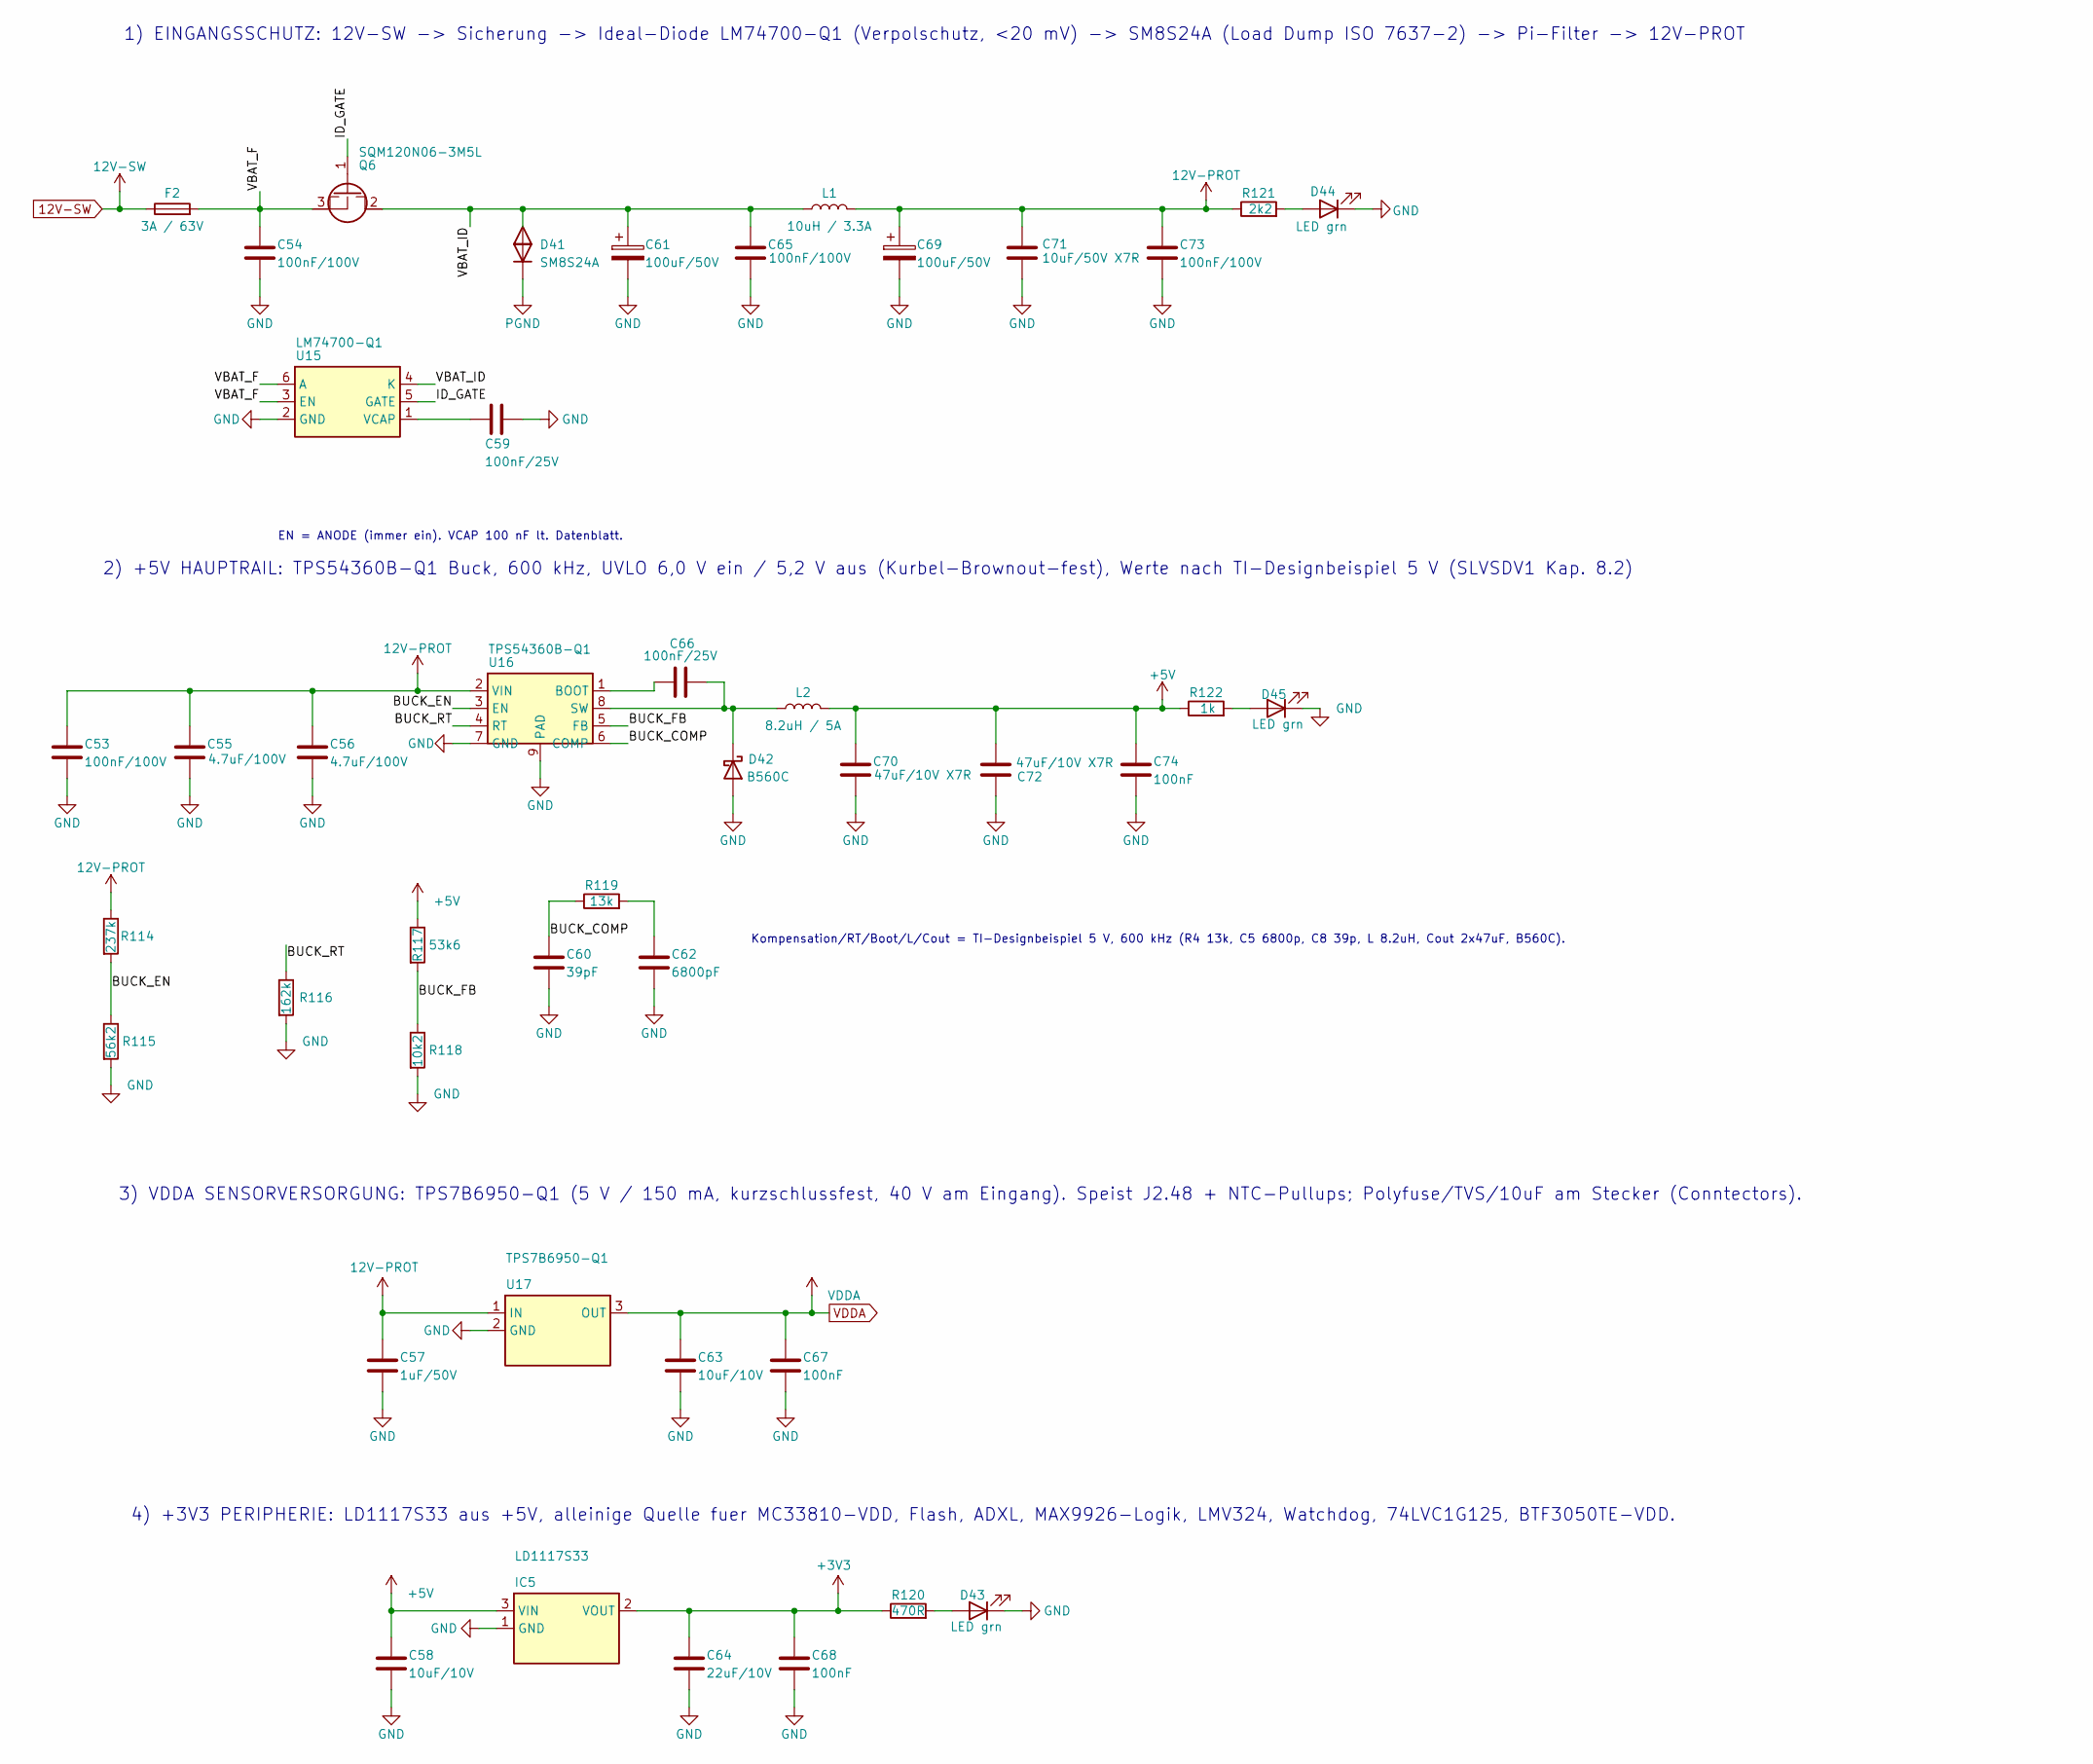
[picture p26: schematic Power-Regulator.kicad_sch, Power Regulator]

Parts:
C53, C54, C65, C73: 100nF/100V; C_1210_3225Metric; Manufacturer_Part_Number C1210C104K1RACTU; Digikey Part Number 399-C1210C104K1RACTUCT-ND
C55, C56: 4.7uF/100V; C_1210_3225Metric; Manufacturer_Part_Number C3225X7S2A475K200AB; Digikey Part Number 445-6042-1-ND
C57: 1uF/50V; C_0805_2012Metric; Manufacturer_Part_Number CC0805KKX7R9BB105; Digikey Part Number 311-1886-1-ND
C58, C63: 10uF/10V; C_0805_2012Metric; Manufacturer_Part_Number CL21A106KPFNNNE; Digikey Part Number 1276-1052-1-ND
C59, C66: 100nF/25V; C_0805_2012Metric; Manufacturer_Part_Number CC0805KRX7R9BB104; Digikey Part Number 311-1140-1-ND
C60: 39pF; C_0805_2012Metric; Manufacturer_Part_Number CC0805JRNPO9BN390; Digikey Part Number 311-1106-1-ND
C61, C69: 100uF/50V; CP_Elec_8x10; Manufacturer_Part_Number EEE-FK1H101GP; Digikey Part Number PCE4323CT-ND
C62: 6800pF; C_0805_2012Metric; Manufacturer_Part_Number CC0805KRX7R9BB682; Digikey Part Number 311-1135-1-ND
C64: 22uF/10V; C_1210_3225Metric; Manufacturer_Part_Number GRM32ER71A226KE20L; Digikey Part Number 490-1876-1-ND
C67, C68, C74: 100nF; C_0805_2012Metric; Manufacturer_Part_Number CC0805KRX7R9BB104; Digikey Part Number 311-1140-1-ND
C70, C72: 47uF/10V X7R; C_1210_3225Metric; Manufacturer_Part_Number CL32A476KOJNNNE; Digikey Part Number 1276-3376-1-ND
C71: 10uF/50V X7R; C_1210_3225Metric; Manufacturer_Part_Number C3225X7R1H106K250AC; Digikey Part Number 445-C3225X7R1H106K250ACCT-ND
D41: SM8S24A; D_DO-218AB; Manufacturer_Part_Number SM8S24A; Digikey Part Number 1655-SM8S24ACT-ND
D42: B560C; D_SMC; Manufacturer_Part_Number B560C-13-F; Digikey Part Number B560C-FDICT-ND
D43, D44, D45: LED grn; LED_0805_2012Metric; Manufacturer_Part_Number LTST-C170GKT; Digikey Part Number 160-1179-1-ND
F2: 3A / 63V; Fuse_1206_3216Metric; Manufacturer_Part_Number 0483003.DR; Digikey Part Number 18-0483003.DRCT-ND
IC5: LD1117S33; SOT-223-3_TabPin2; Manufacturer_Part_Number LD1117S33CTR; Digikey Part Number 497-1241-1-ND
L1: 10uH / 3.3A; L_Bourns_SRR1260; Manufacturer_Part_Number SRR1260-100M; Digikey Part Number SRR1260-100MCT-ND
L2: 8.2uH / 5A; L_Bourns_SRR1260; Manufacturer_Part_Number SRR1260A-8R2Y; Digikey Part Number SRR1260A-8R2YCT-ND
Q6: SQM120N06-3M5L; TO-263-2; Manufacturer_Part_Number SQM120N06-3M5L_GE3; Digikey Part Number SQM120N06-3M5L_GE3CT-ND
R114: 237k; R_0805_2012Metric; Manufacturer_Part_Number RC0805FR-07237KL; Digikey Part Number 311-237KCRCT-ND
R115: 56k2; R_0805_2012Metric; Manufacturer_Part_Number RC0805FR-0756K2L; Digikey Part Number 311-56.2KCRCT-ND
R116: 162k; R_0805_2012Metric; Manufacturer_Part_Number RC0805FR-07162KL; Digikey Part Number 311-162KCRCT-ND
R117: 53k6; R_0805_2012Metric; Manufacturer_Part_Number RC0805FR-0753K6L; Digikey Part Number 311-53.6KCRCT-ND
R118: 10k2; R_0805_2012Metric; Manufacturer_Part_Number RC0805FR-0710K2L; Digikey Part Number 311-10.2KCRCT-ND
R119: 13k; R_0805_2012Metric; Manufacturer_Part_Number RC0805FR-0713KL; Digikey Part Number 311-13.0KCRCT-ND
R120: 470R; R_0805_2012Metric; Manufacturer_Part_Number RC0805FR-07470RL; Digikey Part Number 311-470CRCT-ND
R121: 2k2; R_0805_2012Metric; Manufacturer_Part_Number RC0805FR-072K2L; Digikey Part Number 311-2.20KCRCT-ND
R122: 1k; R_0805_2012Metric; Manufacturer_Part_Number RC0805FR-071KL; Digikey Part Number 311-1.00KCRCT-ND
U15: LM74700-Q1; SOT-23-6; Manufacturer_Part_Number LM74700QDBVRQ1; Digikey Part Number 296-LM74700QDBVRQ1CT-ND
U16: TPS54360B-Q1; HSOP-8-1EP_3.9x4.9mm_P1.27mm_EP2.41x3.1mm_ThermalVias; Manufacturer_Part_Number TPS54360BQDDARQ1; Digikey Part Number 296-46985-1-ND
U17: TPS7B6950-Q1; SOT-223-3_TabPin2; Manufacturer_Part_Number TPS7B6950QDCYRQ1; Digikey Part Number 296-40985-1-ND

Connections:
12V-PROT: C53.1, C55.1, C56.1, C57.1, C69.1, C71.1, C73.1, L1.2, R114.1, R121.1, U16.2 (VIN), U17.1 (IN); also elsewhere on the board
12V-SW: F2.1; also elsewhere on the board
+3V3: C64.1, C68.1, IC5.2 (VOUT), R120.1; also elsewhere on the board
+5V: C58.1, C70.1, C72.1, C74.1, IC5.3 (VIN), L2.2, R117.1, R122.1; also elsewhere on the board
/Power Regulator/BUCK_COMP: C60.1, R119.1, U16.6 (COMP)
/Power Regulator/BUCK_EN: R114.2, R115.1, U16.3 (EN)
/Power Regulator/BUCK_FB: R117.2, R118.1, U16.5 (FB)
/Power Regulator/BUCK_RT: R116.1, U16.4 (RT)
/Power Regulator/ID_GATE: Q6.1 (G), U15.5 (GATE)
/Power Regulator/VBAT_F: C54.1, F2.2, Q6.3 (S), U15.3 (EN), U15.6 (A)
/Power Regulator/VBAT_ID: C61.1, C65.1, D41.1, L1.1, Q6.2 (D), U15.4 (K)
GND: C53.2, C54.2, C55.2, C56.2, C57.2, C58.2, C59.2, C60.2, C61.2, C62.2, C63.2, C64.2, C65.2, C67.2, C68.2, C69.2, C70.2, C71.2, C72.2, C73.2, C74.2, D42.2 (A), D43.1 (K), D44.1 (K), D45.1 (K), IC5.1 (GND), R115.2, R116.2, R118.2, U15.2 (GND), U16.7 (GND), U16.9 (PAD), U17.2 (GND); also elsewhere on the board
unnamed: C62.1, R119.2
unnamed: C66.2, D42.1 (K), L2.1, U16.8 (SW)
unnamed: D43.2 (A), R120.2
unnamed: D44.2 (A), R121.2
unnamed: D45.2 (A), R122.2
unnamed: C59.1, U15.1 (VCAP)
unnamed: C66.1, U16.1 (BOOT)
PGND: D41.2; also elsewhere on the board
VDDA: C63.1, C67.1, U17.3 (OUT); also elsewhere on the board

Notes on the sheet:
EN = ANODE (immer ein). VCAP 100 nF lt. Datenblatt.
1) EINGANGSSCHUTZ: 12V-SW -> Sicherung -> Ideal-Diode LM74700-Q1 (Verpolschutz, <20 mV) -> SM8S24A (Load Dump ISO 7637-2) -> Pi-Filter -> 12V-PROT
2) +5V HAUPTRAIL: TPS54360B-Q1 Buck, 600 kHz, UVLO 6,0 V ein / 5,2 V aus (Kurbel-Brownout-fest), Werte nach TI-Designbeispiel 5 V (SLVSDV1 Kap. 8.2)
3) VDDA SENSORVERSORGUNG: TPS7B6950-Q1 (5 V / 150 mA, kurzschlussfest, 40 V am Eingang). Speist J2.48 + NTC-Pullups; Polyfuse/TVS/10uF am Stecker (Conntectors).
Kompensation/RT/Boot/L/Cout = TI-Designbeispiel 5 V, 600 kHz (R4 13k, C5 6800p, C8 39p, L 8.2uH, Cout 2x47uF, B560C).
4) +3V3 PERIPHERIE: LD1117S33 aus +5V, alleinige Quelle fuer MC33810-VDD, Flash, ADXL, MAX9926-Logik, LMV324, Watchdog, 74LVC1G125, BTF3050TE-VDD.

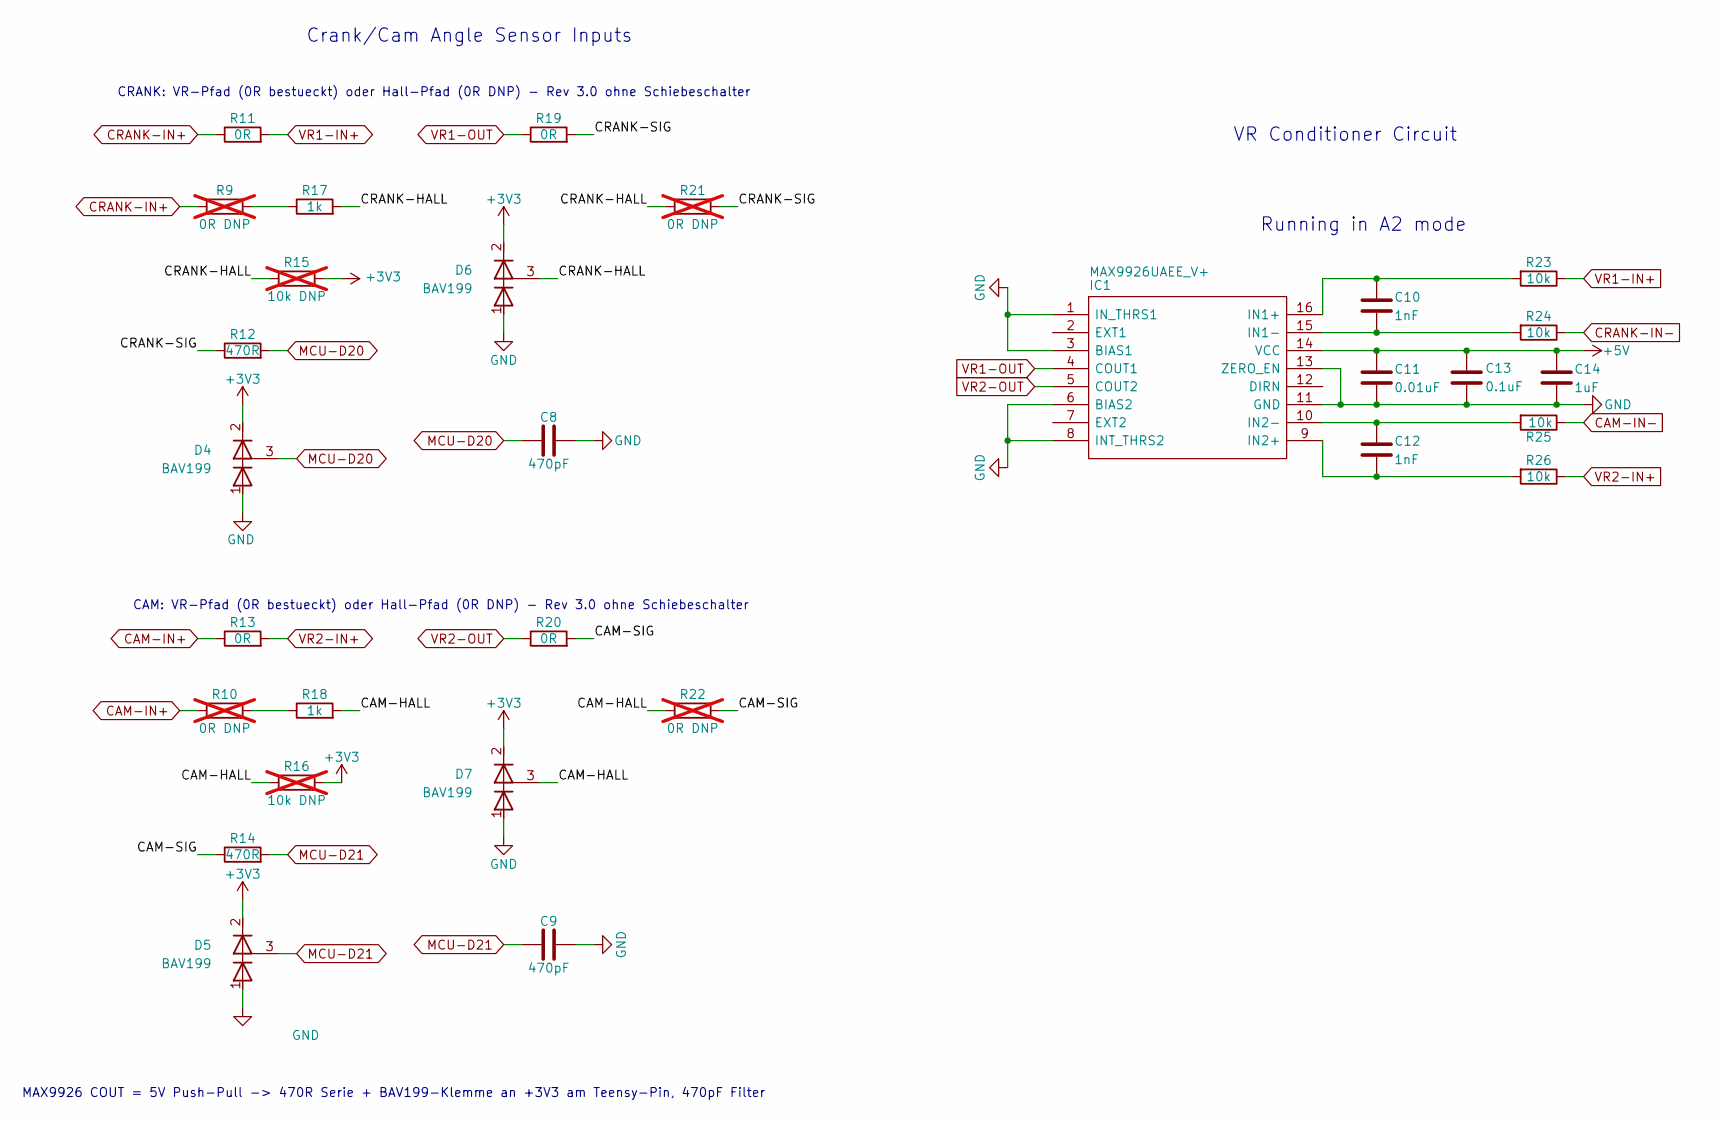
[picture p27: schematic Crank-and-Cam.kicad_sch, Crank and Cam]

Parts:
C8, C9: 470pF; C_0805_2012Metric; Manufacturer_Part_Number CC0805KRX7R9BB471; Digikey Part Number 311-1124-1-ND
C10, C12: 1nF; C_0805_2012Metric; Manufacturer_Part_Number C0805C102J5HACAUTO; Digikey Part Number 399-16591-1-ND
C11: 0.01uF; C_0805_2012Metric; Manufacturer_Part_Number CC0805KRX7R9BB103; Digikey Part Number 311-1136-1-ND
C13: 0.1uF; C_0805_2012Metric; Manufacturer_Part_Number CC0805KRX7R9BB104; Digikey Part Number 311-1140-1-ND
C14: 1uF; C_0805_2012Metric; Manufacturer_Part_Number CC0805KKX7R7BB105; Digikey Part Number 311-1365-1-ND
D4, D5, D6, D7: BAV199; SOT-23; Manufacturer_Part_Number BAV199LT1G; Digikey Part Number BAV199LT1GOSCT-ND
IC1: MAX9926UAEE_V+; QSOP-16_3.9x4.9mm_P0.635mm; Manufacturer_Part_Number MAX9926UAEE/V+; Mouser Part Number 700-MAX9926UAEE/V+
R9, R10, R21, R22: 0R DNP; R_0805_2012Metric; Manufacturer_Part_Number RC0805JR-070RL; Digikey Part Number 311-0.0ARCT-ND; not fitted
R11, R13, R19, R20: 0R; R_0805_2012Metric; Manufacturer_Part_Number RC0805JR-070RL; Digikey Part Number 311-0.0ARCT-ND
R12, R14: 470R; R_0805_2012Metric; Manufacturer_Part_Number RC0805FR-07470RL; Digikey Part Number 311-470CRCT-ND
R15, R16: 10k DNP; R_0805_2012Metric; Manufacturer_Part_Number RC0805FR-0710KL; Digikey Part Number 311-10.0KCRCT-ND; not fitted
R17, R18: 1k; R_0805_2012Metric; Manufacturer_Part_Number RC0805FR-071KL; Digikey Part Number 311-1.00KCRCT-ND
R23, R24, R25, R26: 10k; R_1206_3216Metric; Manufacturer_Part_Number RC1206FR-7W10KL; Digikey Part Number 13-RC1206FR-7W10KLTR-ND

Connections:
+3V3: D4.2 (K2), D5.2 (K2), D6.2 (K2), D7.2 (K2), R15.2, R16.2; also elsewhere on the board
+5V: C11.1, C13.1, C14.1, IC1.14 (VCC); also elsewhere on the board
/Crank and Cam/CAM-HALL: D7.3 (K1A2), R16.1, R18.2, R22.1
/Crank and Cam/CAM-SIG: R14.1, R20.2, R22.2
/Crank and Cam/CRANK-HALL: D6.3 (K1A2), R15.1, R17.2, R21.1
/Crank and Cam/CRANK-SIG: R12.1, R19.2, R21.2
CAM-IN+: R10.1, R13.1; also elsewhere on the board
CAM-IN-: R25.1; also elsewhere on the board
CRANK-IN+: R9.1, R11.1; also elsewhere on the board
CRANK-IN-: R24.1; also elsewhere on the board
GND: C8.2, C9.2, C11.2, C13.2, C14.2, D4.1 (A1), D5.1 (A1), D6.1 (A1), D7.1 (A1), IC1.1 (IN_THRS1), IC1.3 (BIAS1), IC1.6 (BIAS2), IC1.8 (INT_THRS2), IC1.11 (GND), IC1.13 (ZERO_EN); also elsewhere on the board
MCU-D20: C8.1, D4.3 (K1A2), R12.2; also elsewhere on the board
MCU-D21: C9.1, D5.3 (K1A2), R14.2; also elsewhere on the board
unnamed: C10.1, IC1.16 (IN1+), R23.2
unnamed: C10.2, IC1.15 (IN1-), R24.2
unnamed: C12.2, IC1.9 (IN2+), R26.2
unnamed: C12.1, IC1.10 (IN2-), R25.2
unnamed: R10.2, R18.1
unnamed: R9.2, R17.1
VR1-IN+: R11.2, R23.1
VR1-OUT: IC1.4 (COUT1), R19.1
VR2-IN+: R13.2, R26.1
VR2-OUT: IC1.5 (COUT2), R20.1

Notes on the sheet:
CRANK: VR-Pfad (0R bestueckt) oder Hall-Pfad (0R DNP) - Rev 3.0 ohne Schiebeschalter
VR Conditioner Circuit
Crank/Cam Angle Sensor Inputs
Running in A2 mode
MAX9926 COUT = 5V Push-Pull -> 470R Serie + BAV199-Klemme an +3V3 am Teensy-Pin, 470pF Filter
CAM: VR-Pfad (0R bestueckt) oder Hall-Pfad (0R DNP) - Rev 3.0 ohne Schiebeschalter

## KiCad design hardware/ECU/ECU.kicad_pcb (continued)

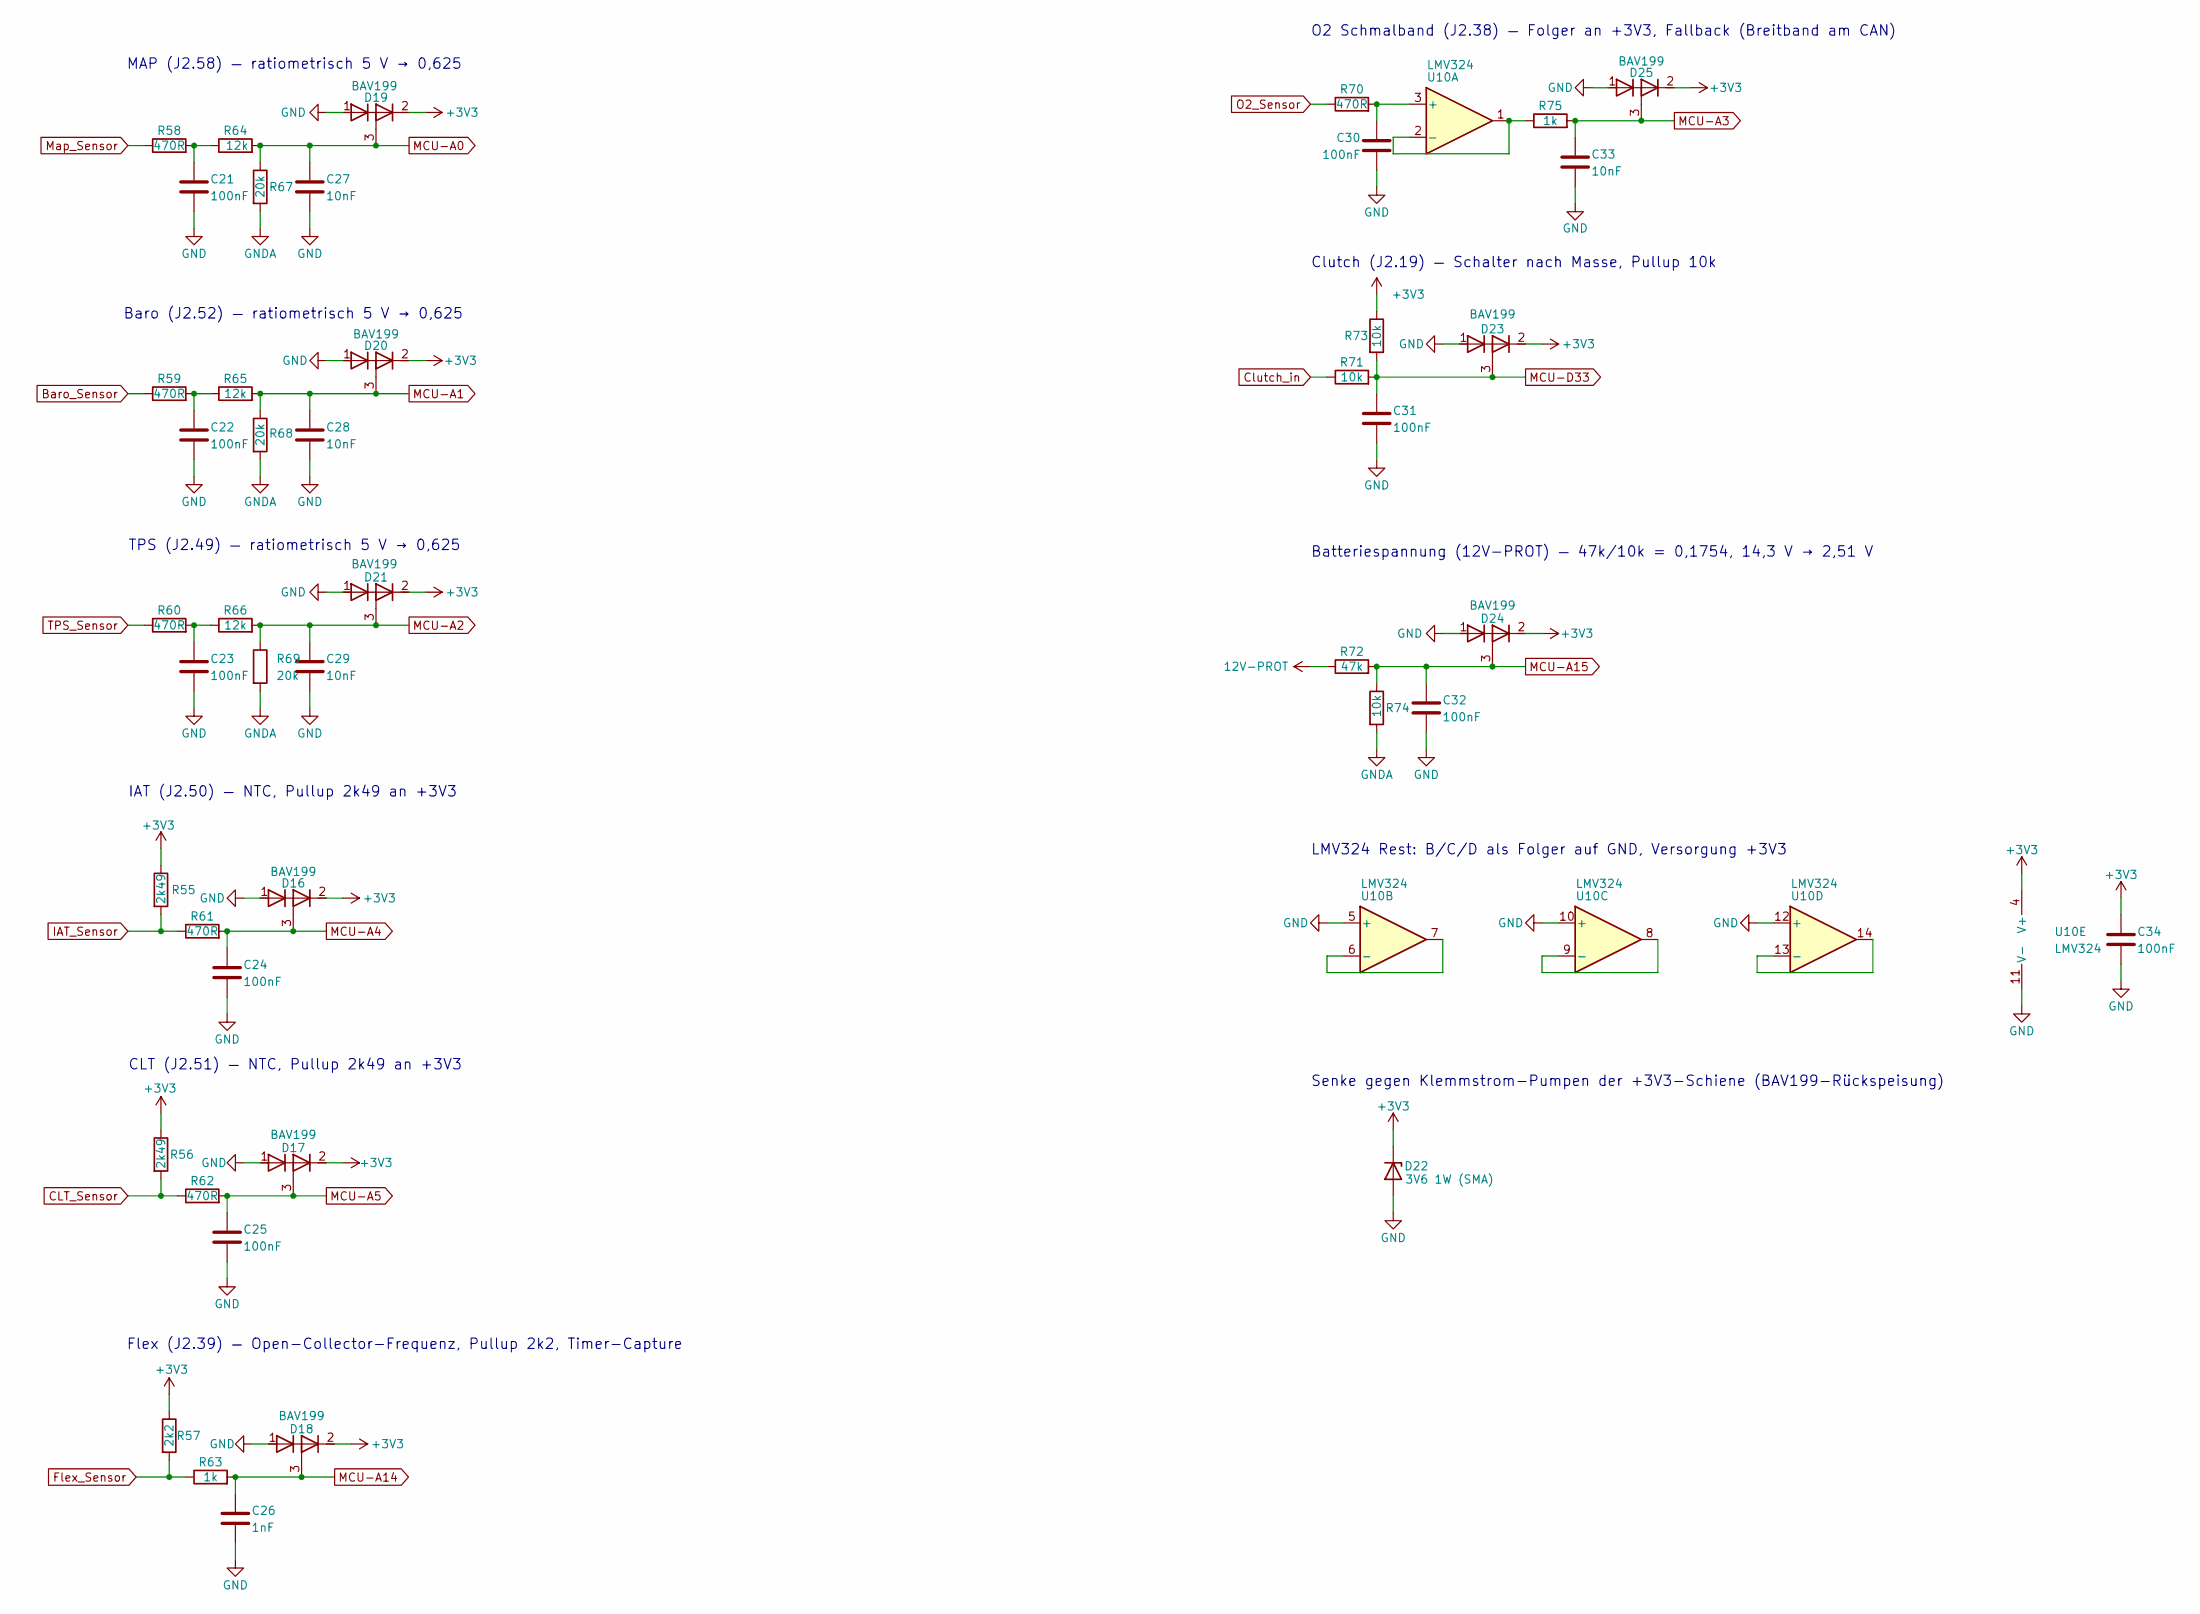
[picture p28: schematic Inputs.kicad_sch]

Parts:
C21, C22, C23, C24, C25, C30, C31, C32, C34: 100nF; C_0805_2012Metric; Manufacturer_Part_Number CC0805KRX7R9BB104; Digikey Part Number 311-1140-1-ND
C26: 1nF; C_0805_2012Metric; Manufacturer_Part_Number C0805C102J5HACAUTO; Digikey Part Number 399-16591-1-ND
C27, C28, C29, C33: 10nF; C_0805_2012Metric; Manufacturer_Part_Number CC0805KRX7R9BB103; Digikey Part Number 311-1136-1-ND
D16, D17, D18, D19, D20, D21, D23, D24, D25: BAV199; SOT-23; Manufacturer_Part_Number BAV199LT1G; Digikey Part Number BAV199LT1GOSCT-ND
D22: 3V6 1W (SMA); D_SMA; Manufacturer_Part_Number 1SMA5914BT3G; Digikey Part Number 1SMA5914BT3GOSCT-ND
R55, R56: 2k49; R_0805_2012Metric; Manufacturer_Part_Number RC0805FR-072K49L; Digikey Part Number 311-2.49KCRCT-ND
R57: 2k2; R_0805_2012Metric; Manufacturer_Part_Number RC0805FR-072K2L; Digikey Part Number 311-2.20KCRCT-ND
R58, R59, R60, R61, R62, R70: 470R; R_0805_2012Metric; Manufacturer_Part_Number RC0805FR-07470RL; Digikey Part Number 311-470CRCT-ND
R63, R75: 1k; R_0805_2012Metric; Manufacturer_Part_Number RC0805FR-071KL; Digikey Part Number 311-1.00KCRCT-ND
R64, R65, R66: 12k; R_0805_2012Metric; Manufacturer_Part_Number RC0805FR-0712KL; Digikey Part Number 311-12.0KCRCT-ND
R67, R68, R69: 20k; R_0805_2012Metric; Manufacturer_Part_Number RC0805FR-0720KL; Digikey Part Number 311-20.0KCRCT-ND
R71, R73, R74: 10k; R_0805_2012Metric; Manufacturer_Part_Number RC0805FR-0710KL; Digikey Part Number 311-10.0KCRCT-ND
R72: 47k; R_0805_2012Metric; Manufacturer_Part_Number RC0805FR-0747KL; Digikey Part Number 311-47.0KCRCT-ND
U10: LMV324; SOIC-14_3.9x8.7mm_P1.27mm; Manufacturer_Part_Number LMV324IDR; Digikey Part Number 296-9569-1-ND

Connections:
12V-PROT: R72.1; also elsewhere on the board
+3V3: C34.1, D16.2 (K2), D17.2 (K2), D18.2 (K2), D19.2 (K2), D20.2 (K2), D21.2 (K2), D22.1 (K), D23.2 (K2), D24.2 (K2), D25.2 (K2), R55.1, R56.1, R57.1, R73.1, U10.4 (V+); also elsewhere on the board
Baro_Sensor: R59.1; also elsewhere on the board
CLT_Sensor: R56.2, R62.1; also elsewhere on the board
Clutch_in: R71.1; also elsewhere on the board
Flex_Sensor: R57.2, R63.1; also elsewhere on the board
GND: C21.2, C22.2, C23.2, C24.2, C25.2, C26.2, C27.2, C28.2, C29.2, C30.2, C31.2, C32.2, C33.2, C34.2, D16.1 (A1), D17.1 (A1), D18.1 (A1), D19.1 (A1), D20.1 (A1), D21.1 (A1), D22.2 (A), D23.1 (A1), D24.1 (A1), D25.1 (A1), U10.5 (+), U10.10 (+), U10.11 (V-), U10.12 (+); also elsewhere on the board
GNDA: R67.2, R68.2, R69.2, R74.2; also elsewhere on the board
IAT_Sensor: R55.2, R61.1; also elsewhere on the board
MCU-A0: C27.1, D19.3 (K1A2), R64.2, R67.1; also elsewhere on the board
MCU-A1: C28.1, D20.3 (K1A2), R65.2, R68.1; also elsewhere on the board
MCU-A2: C29.1, D21.3 (K1A2), R66.2, R69.1; also elsewhere on the board
MCU-A3: C33.1, D25.3 (K1A2), R75.2; also elsewhere on the board
MCU-A4: C24.1, D16.3 (K1A2), R61.2; also elsewhere on the board
MCU-A5: C25.1, D17.3 (K1A2), R62.2; also elsewhere on the board
MCU-A14: C26.1, D18.3 (K1A2), R63.2; also elsewhere on the board
MCU-A15: C32.1, D24.3 (K1A2), R72.2, R74.1; also elsewhere on the board
MCU-D33: C31.1, D23.3 (K1A2), R71.2, R73.2; also elsewhere on the board
Map_Sensor: R58.1; also elsewhere on the board
unnamed: C21.1, R58.2, R64.1
unnamed: C22.1, R59.2, R65.1
unnamed: C23.1, R60.2, R66.1
unnamed: C30.1, R70.2, U10.3 (+)
unnamed: R75.1, U10.1, U10.2 (-)
unnamed: U10.6 (-), U10.7
unnamed: U10.8, U10.9 (-)
unnamed: U10.13 (-), U10.14
O2_Sensor: R70.1; also elsewhere on the board
TPS_Sensor: R60.1; also elsewhere on the board

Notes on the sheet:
Senke gegen Klemmstrom-Pumpen der +3V3-Schiene (BAV199-Rückspeisung)
Flex (J2.39) — Open-Collector-Frequenz, Pullup 2k2, Timer-Capture
Baro (J2.52) — ratiometrisch 5 V → 0,625
LMV324 Rest: B/C/D als Folger auf GND, Versorgung +3V3
O2 Schmalband (J2.38) — Folger an +3V3, Fallback (Breitband am CAN)
MAP (J2.58) — ratiometrisch 5 V → 0,625
Batteriespannung (12V-PROT) — 47k/10k = 0,1754, 14,3 V → 2,51 V
TPS (J2.49) — ratiometrisch 5 V → 0,625
Clutch (J2.19) — Schalter nach Masse, Pullup 10k
IAT (J2.50) — NTC, Pullup 2k49 an +3V3
CLT (J2.51) — NTC, Pullup 2k49 an +3V3

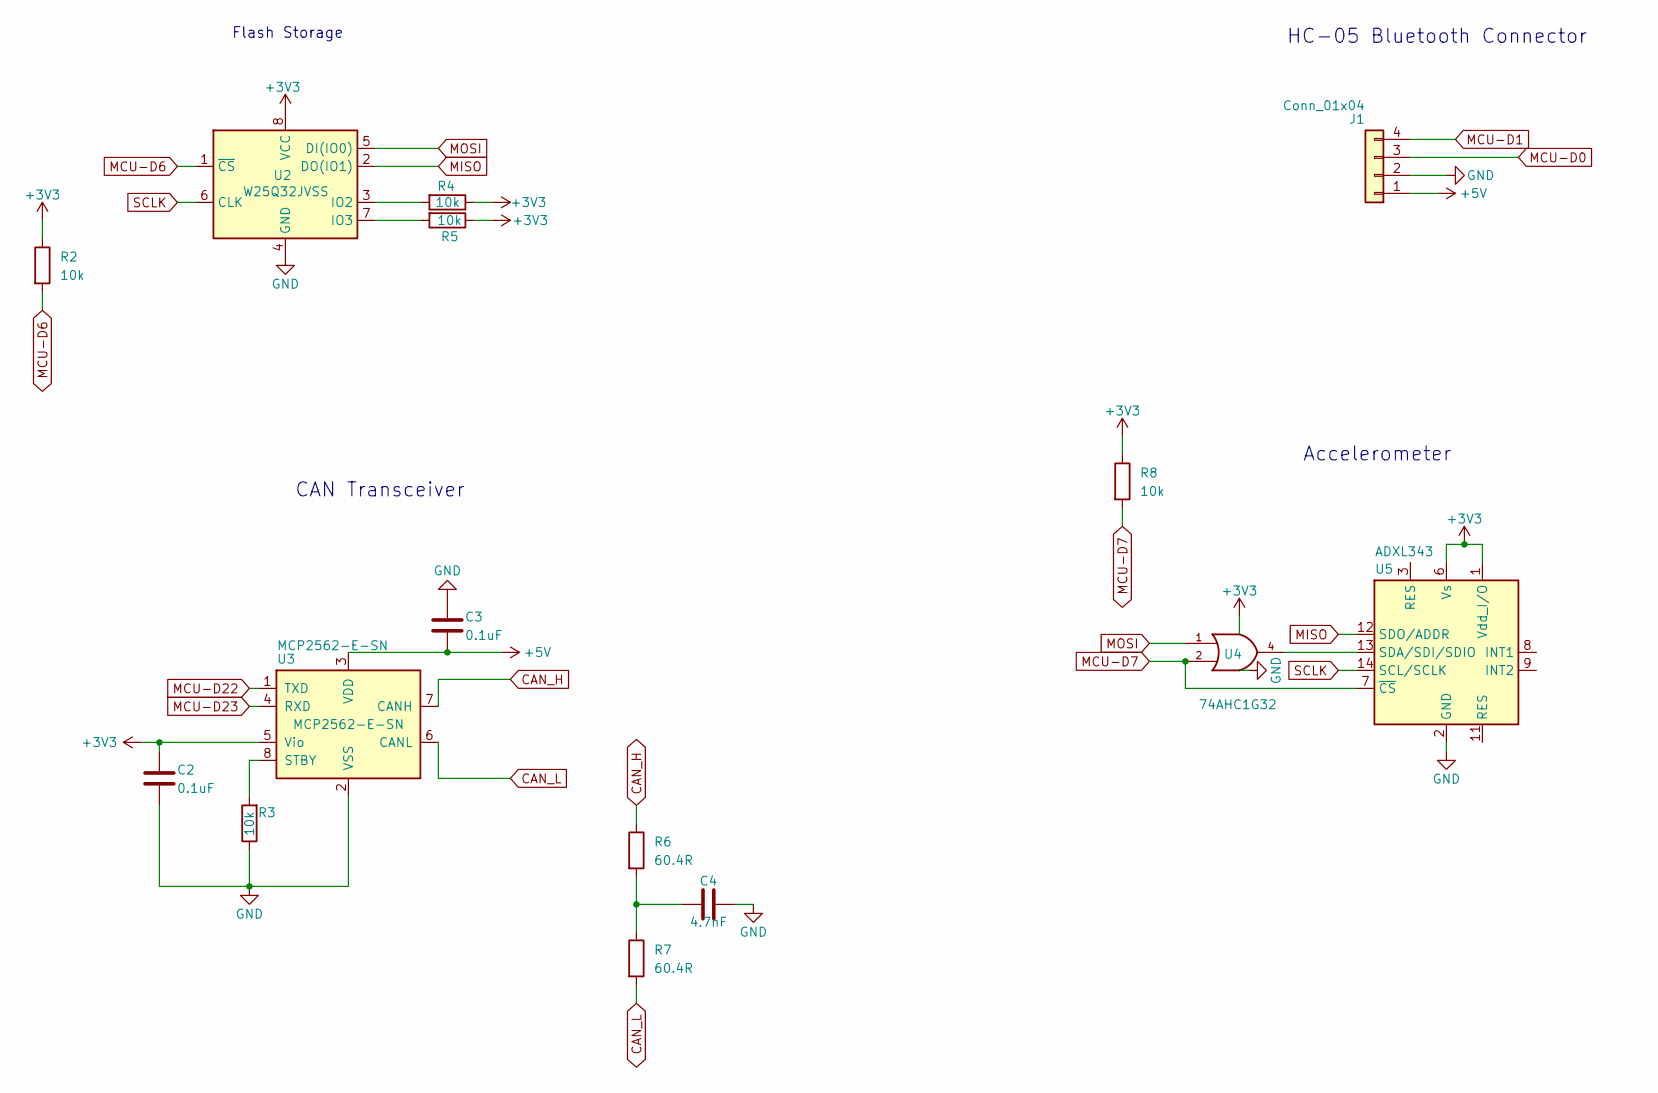
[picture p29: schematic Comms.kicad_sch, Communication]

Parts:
C2, C3: 0.1uF; C_0805_2012Metric; Manufacturer_Part_Number CC0805KRX7R9BB104; Digikey Part Number 311-1140-1-ND
C4: 4.7nF; C_0805_2012Metric; Manufacturer_Part_Number CC0805KRX7R9BB472; Digikey Part Number 311-1133-1-ND
J1: Conn_01x04; PinHeader_1x04_P2.54mm_Vertical; Manufacturer_Part_Number 61300411121; Digikey Part Number 732-5317-ND
R2, R3, R4, R5, R8: 10k; R_0805_2012Metric; Manufacturer_Part_Number RC0805FR-0710KL; Digikey Part Number 311-10.0KCRCT-ND
R6, R7: 60.4R; R_0805_2012Metric; Manufacturer_Part_Number RC0805FR-0760R4L; Digikey Part Number 311-60.4CRCT-ND
U2: W25Q32JVSS; SOIC-8_5.3x5.3mm_P1.27mm; Manufacturer_Part_Number W25Q32RVCSJQ TR; Digikey Part Number 256-W25Q32RVCSJQTR-ND
U3: MCP2562-E-SN; SOIC-8_3.9x4.9mm_P1.27mm; Manufacturer_Part_Number MCP2562-E/SN; Digikey Part Number MCP2562-E/SN-ND
U4: 74AHC1G32; SOT-353_SC-70-5; Manufacturer_Part_Number SN74AHC1G32DCKR; Digikey Part Number 296-8749-1-ND
U5: ADXL343; LGA-14_3x5mm_P0.8mm_LayoutBorder1x6y; Manufacturer_Part_Number ADXL343BCCZ-RL; Digikey Part Number ADXL343BCCZ-RLCT-ND

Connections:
+3V3: C2.1, R2.1, R4.1, R5.1, R8.1, U2.8 (VCC), U3.5 (Vio), U4.5 (VCC), U5.1 (Vdd_I/O), U5.6 (Vs); also elsewhere on the board
+5V: C3.2, J1.1, U3.3 (VDD); also elsewhere on the board
CAN_H: R6.1, U3.7 (CANH); also elsewhere on the board
CAN_L: R7.2, U3.6 (CANL); also elsewhere on the board
GND: C2.2, C3.1, C4.2, J1.2, R3.1, U2.4 (GND), U3.2 (VSS), U4.3 (GND), U5.2 (GND), U5.4 (GND), U5.5 (GND); also elsewhere on the board
MCU-D0: J1.3; also elsewhere on the board
MCU-D1: J1.4; also elsewhere on the board
MCU-D6: R2.2, U2.1 (~CS); also elsewhere on the board
MCU-D7: R8.2, U4.2, U5.7 (~CS); also elsewhere on the board
MCU-D22: U3.1 (TXD); also elsewhere on the board
MCU-D23: U3.4 (RXD); also elsewhere on the board
MISO: U2.2 (DO(IO1)), U5.12 (SDO/ADDR); also elsewhere on the board
MOSI: U2.5 (DI(IO0)), U4.1; also elsewhere on the board
unnamed: C4.1, R6.2, R7.1
unnamed: R4.2, U2.3 (IO2)
unnamed: R5.2, U2.7 (IO3)
unnamed: R3.2, U3.8 (STBY)
unnamed: U4.4, U5.13 (SDA/SDI/SDIO)
SCLK: U2.6 (CLK), U5.14 (SCL/SCLK); also elsewhere on the board

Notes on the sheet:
Flash Storage
CAN Transceiver
HC-05 Bluetooth Connector
Accelerometer

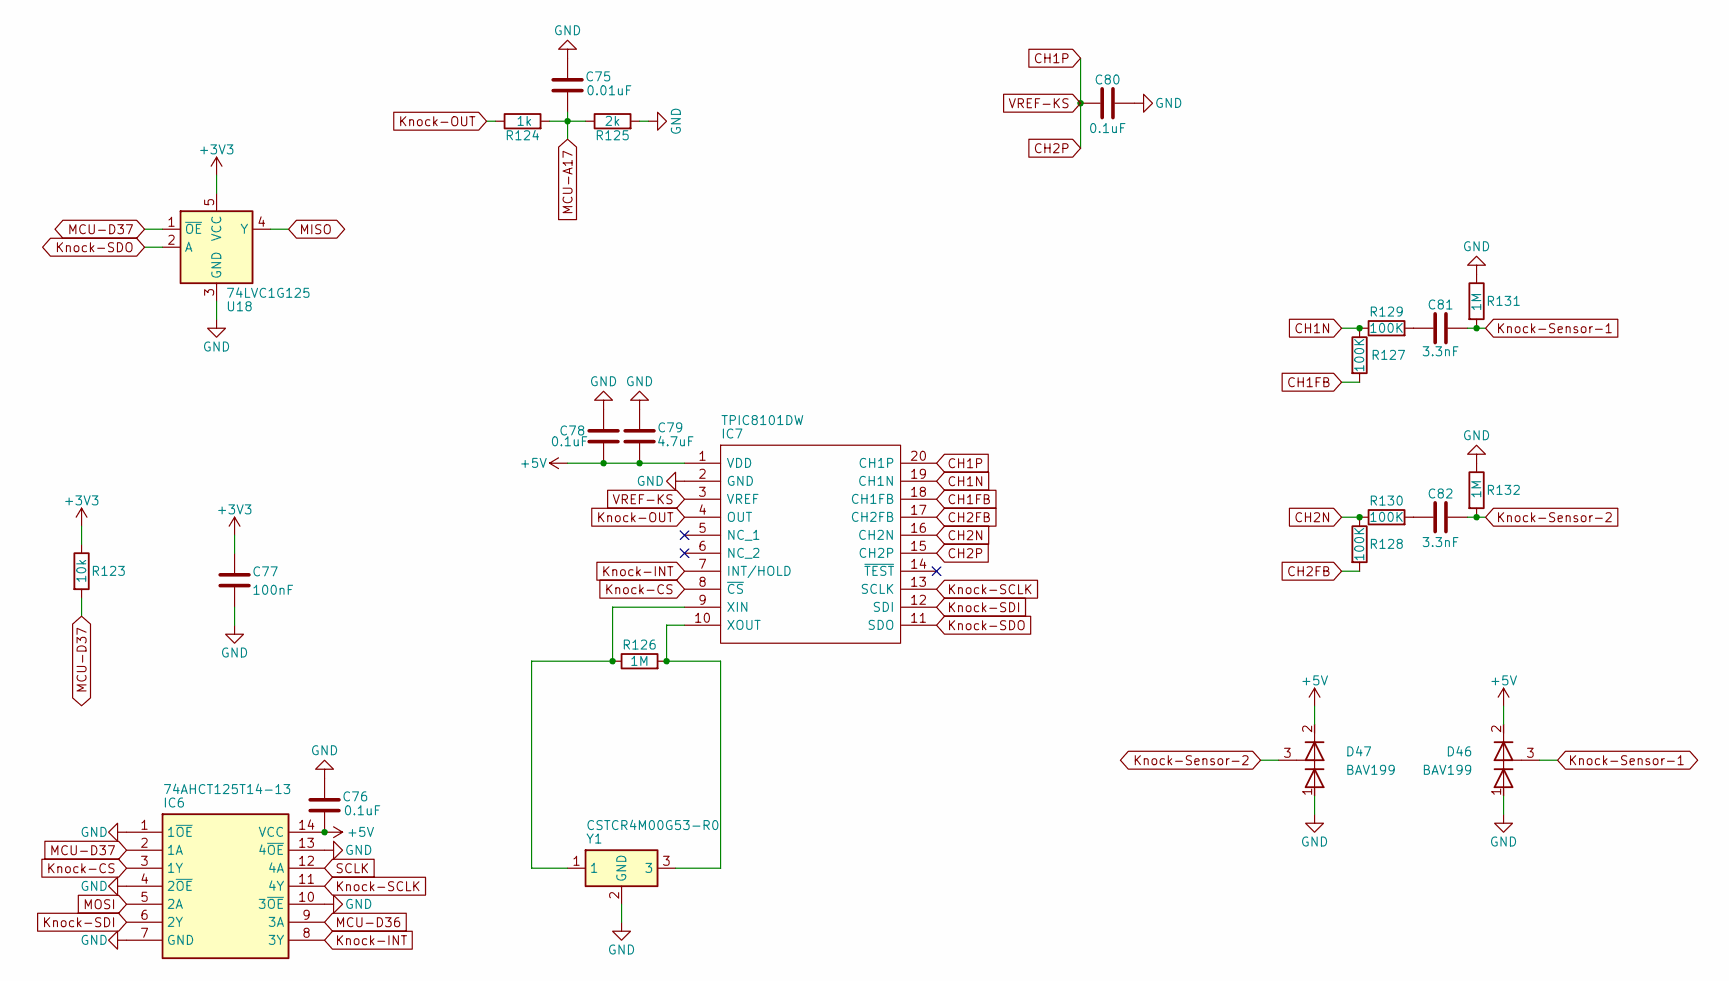
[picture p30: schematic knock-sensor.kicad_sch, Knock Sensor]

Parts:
C75: 0.01uF; C_0805_2012Metric; Manufacturer_Part_Number CC0805KRX7R9BB103; Digikey Part Number 311-1136-1-ND
C76, C78, C80: CC0805KRX7R9BB104; C_0805_2012Metric; Mouser Part Number 603-CC805KRX7R9BB104
C77: 100nF; C_0805_2012Metric; Manufacturer_Part_Number CC0805KRX7R9BB104; Digikey Part Number 311-1140-1-ND
C79: CC0805KKX7R7BB475; C_0805_2012Metric; Mouser Part Number 603-CC805KKX7R7BB475
C81, C82: CC0805JRX7R9BB332; C_0805_2012Metric; Manufacturer_Part_Number CC0805JRX7R9BB332; Digikey Part Number 311-4277-1-ND
D46, D47: BAV199; SOT-23; Manufacturer_Part_Number BAV199LT1G; Digikey Part Number BAV199LT1GOSCT-ND
IC6: 74AHCT125T14-13; TSSOP-14_4.4x5mm_P0.65mm; Manufacturer_Part_Number 74AHCT125T14-13; Mouser Part Number 621-74AHCT125T14-13
IC7: TPIC8101DW; SOIC-20W_7.5x12.8mm_P1.27mm; Manufacturer_Part_Number TPIC8101DWR; Mouser Part Number 595-TPIC8101DW
R123: 10k; R_0805_2012Metric; Manufacturer_Part_Number RC0805FR-0710KL; Digikey Part Number 311-10.0KCRCT-ND
R124: 1k; R_0805_2012Metric; Manufacturer_Part_Number RC0805FR-071KL; Digikey Part Number 311-1.00KCRCT-ND
R125: 2k; R_0805_2012Metric; Manufacturer_Part_Number RC0805FR-072KL; Mouser Part Number 603-RC0805FR-072KL
R126, R131, R132: RC0805FR-071ML; R_0805_2012Metric; Mouser Part Number 603-RC0805FR-071ML
R127, R128, R129, R130: RC0805FR-07100KL; R_0805_2012Metric; Mouser Part Number 603-RC0805FR-07100KL
U18: 74LVC1G125; SOT-353_SC-70-5; Manufacturer_Part_Number SN74LVC1G125DCKR; Digikey Part Number 296-11604-1-ND
Y1: CSTCR4M00G53-R0; Resonator_SMD_Murata_CSTCR_4.5x2x1.15mm; Manufacturer_Part_Number CSTCR4M00G53-R0; Digikey Part Number 490-1200-1-ND

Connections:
+3V3: C77.1, R123.1, U18.5 (VCC); also elsewhere on the board
+5V: C76.2, C78.2, C79.2, D46.2 (K2), D47.2 (K2), IC6.14 (VCC), IC7.1 (VDD); also elsewhere on the board
CH1FB: IC7.18 (CH1FB), R127.2
CH1N: IC7.19 (CH1N), R127.1, R129.1
CH1P: C80.1, IC7.3 (VREF), IC7.15 (CH2P), IC7.20 (CH1P)
CH2FB: IC7.17 (CH2FB), R128.2
CH2N: IC7.16 (CH2N), R128.1, R130.1
GND: C75.1, C76.1, C77.2, C78.1, C79.1, C80.2, D46.1 (A1), D47.1 (A1), IC6.1 (1~OE), IC6.4 (2~OE), IC6.7 (GND), IC6.10 (3~OE), IC6.13 (4~OE), IC7.2 (GND), R125.2, R131.1, R132.1, U18.3 (GND), Y1.2 (GND); also elsewhere on the board
Knock-CS: IC6.3 (1Y), IC7.8 (~CS)
Knock-INT: IC6.8 (3Y), IC7.7 (INT/HOLD)
Knock-OUT: IC7.4 (OUT), R124.1
Knock-SCLK: IC6.11 (4Y), IC7.13 (SCLK)
Knock-SDI: IC6.6 (2Y), IC7.12 (SDI)
Knock-SDO: IC7.11 (SDO), U18.2 (A)
Knock-Sensor-1: C81.2, D46.3 (K1A2), R131.2; also elsewhere on the board
Knock-Sensor-2: C82.2, D47.3 (K1A2), R132.2; also elsewhere on the board
MCU-A17: C75.2, R124.2, R125.1; also elsewhere on the board
MCU-D36: IC6.9 (3A); also elsewhere on the board
MCU-D37: IC6.2 (1A), R123.2, U18.1 (~OE); also elsewhere on the board
MISO: U18.4 (Y); also elsewhere on the board
MOSI: IC6.5 (2A); also elsewhere on the board
unnamed: C81.1, R129.2
unnamed: C82.1, R130.2
unnamed: IC7.9 (XIN), R126.1, Y1.1
unnamed: IC7.10 (XOUT), R126.2, Y1.3
SCLK: IC6.12 (4A); also elsewhere on the board

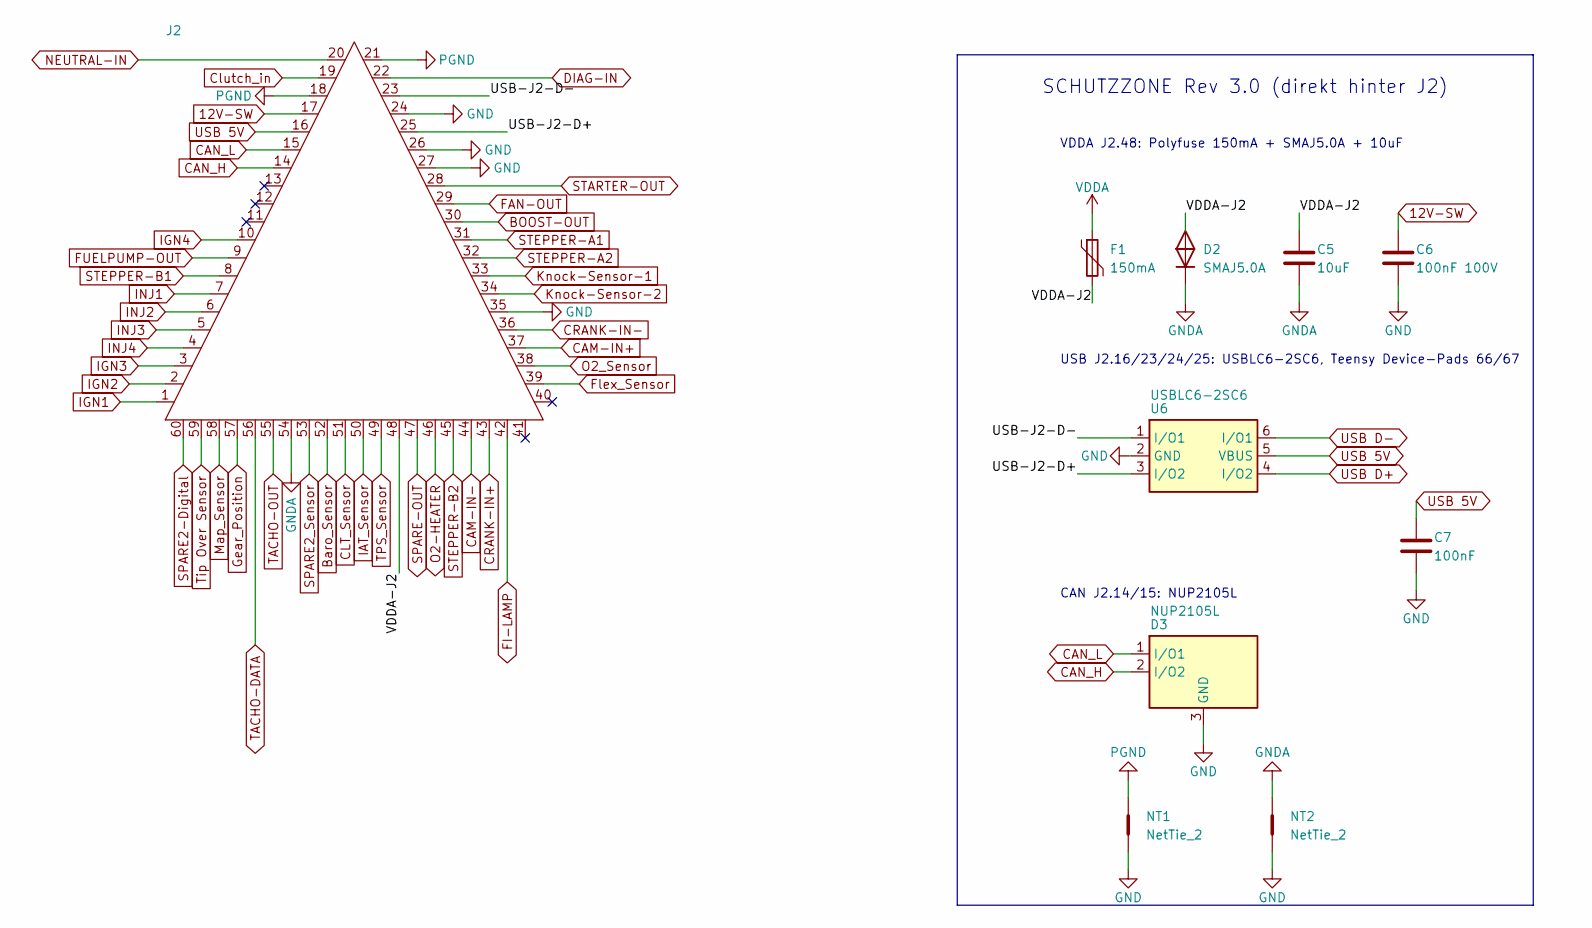
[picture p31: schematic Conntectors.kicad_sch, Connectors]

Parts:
C5: 10uF; C_1206_3216Metric; Manufacturer_Part_Number GRM31CR71E106KA12L; Digikey Part Number 490-6518-1-ND
C6: 100nF 100V; C_1206_3216Metric; Manufacturer_Part_Number C1206C104K1RACTU; Digikey Part Number 399-C1206C104K1RACTUCT-ND
C7: 100nF; C_0805_2012Metric; Manufacturer_Part_Number CC0805KRX7R9BB104; Digikey Part Number 311-1140-1-ND
D2: SMAJ5.0A; D_SMA; Manufacturer_Part_Number SMAJ5.0A; Digikey Part Number SMAJ5.0ALFCT-ND
D3: NUP2105L; SOT-23; Manufacturer_Part_Number NUP2105LT1G; Digikey Part Number NUP2105LT1GOSCT-ND
F1: 150mA; Fuse_1812_4532Metric; Manufacturer_Part_Number 1812L014DR; Digikey Part Number F3353CT-ND
J2: 6437288-3; Manufacturer_Part_Number 6437288-3; Digikey Part Number A122211-ND
NT1, NT2: NetTie_2; NetTie-2_SMD_Pad0.5mm
U6: USBLC6-2SC6; SOT-23-6; Manufacturer_Part_Number USBLC6-2SC6; Digikey Part Number 497-5235-1-ND

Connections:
12V-SW: C6.1, J2.17; also elsewhere on the board
/Conntectors/USB-J2-D+: J2.25, U6.3 (I/O2)
/Conntectors/USB-J2-D-: J2.23, U6.1 (I/O1)
/Conntectors/VDDA-J2: C5.1, D2.1, F1.2, J2.48
BOOST-OUT: J2.30; also elsewhere on the board
Baro_Sensor: J2.52; also elsewhere on the board
CAM-IN+: J2.37; also elsewhere on the board
CAM-IN-: J2.44; also elsewhere on the board
CAN_H: D3.2 (I/O2), J2.14; also elsewhere on the board
CAN_L: D3.1 (I/O1), J2.15; also elsewhere on the board
CLT_Sensor: J2.51; also elsewhere on the board
CRANK-IN+: J2.43; also elsewhere on the board
CRANK-IN-: J2.36; also elsewhere on the board
Clutch_in: J2.19; also elsewhere on the board
DIAG-IN: J2.22
FAN-OUT: J2.29; also elsewhere on the board
FI-LAMP: J2.42; also elsewhere on the board
FUELPUMP-OUT: J2.9; also elsewhere on the board
Flex_Sensor: J2.39; also elsewhere on the board
GND: C6.2, C7.2, D3.3 (GND), J2.24, J2.26, J2.27, J2.35, NT1.2, NT2.2, U6.2 (GND); also elsewhere on the board
GNDA: C5.2, D2.2, J2.54, NT2.1; also elsewhere on the board
Gear_Position: J2.57; also elsewhere on the board
IAT_Sensor: J2.50; also elsewhere on the board
IGN1: J2.1; also elsewhere on the board
IGN2: J2.2; also elsewhere on the board
IGN3: J2.3; also elsewhere on the board
IGN4: J2.10; also elsewhere on the board
INJ1: J2.7; also elsewhere on the board
INJ2: J2.6; also elsewhere on the board
INJ3: J2.5; also elsewhere on the board
INJ4: J2.4; also elsewhere on the board
Knock-Sensor-1: J2.33; also elsewhere on the board
Knock-Sensor-2: J2.34; also elsewhere on the board
Map_Sensor: J2.58; also elsewhere on the board
NEUTRAL-IN: J2.20; also elsewhere on the board
O2-HEATER: J2.46; also elsewhere on the board
O2_Sensor: J2.38; also elsewhere on the board
PGND: J2.18, J2.21, NT1.1; also elsewhere on the board
SPARE2-Digital: J2.60; also elsewhere on the board
SPARE2_Sensor: J2.53; also elsewhere on the board
SPARE-OUT: J2.47; also elsewhere on the board
STARTER-OUT: J2.28; also elsewhere on the board
STEPPER-A1: J2.31; also elsewhere on the board
STEPPER-A2: J2.32; also elsewhere on the board
STEPPER-B1: J2.8; also elsewhere on the board
STEPPER-B2: J2.45; also elsewhere on the board
TACHO-DATA: J2.56
TACHO-OUT: J2.55; also elsewhere on the board
TPS_Sensor: J2.49; also elsewhere on the board
Tip Over Sensor: J2.59; also elsewhere on the board
USB 5V: C7.1, J2.16, U6.5 (VBUS)
USB D+: U6.4 (I/O2); also elsewhere on the board
USB D-: U6.6 (I/O1); also elsewhere on the board
VDDA: F1.1; also elsewhere on the board

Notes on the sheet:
SCHUTZZONE Rev 3.0 (direkt hinter J2)
VDDA J2.48: Polyfuse 150mA + SMAJ5.0A + 10uF
USB J2.16/23/24/25: USBLC6-2SC6, Teensy Device-Pads 66/67
CAN J2.14/15: NUP2105L

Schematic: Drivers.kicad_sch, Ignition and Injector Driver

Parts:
C15, C17: 0.1uF; C_0805_2012Metric; Manufacturer_Part_Number CC0805KRX7R9BB104; Digikey Part Number 311-1140-1-ND
C16, C18: 33uF; CP_Elec_6.3x7.7; Voltage 50V; Manufacturer_Part_Number EEE-1HA330XP; Digikey Part Number PCE3925CT-ND
C19, C20: 100n; C_0805_2012Metric; Manufacturer_Part_Number CC0805KRX7R9BB104; Digikey Part Number 311-1140-1-ND
D8, D9, D14, D15: LED; LED_0805_2012Metric; Manufacturer_Part_Number LTST-C170KRKT; Digikey Part Number 160-1415-1-ND
D10, D11, D12, D13: D; D_SOD-323; Manufacturer_Part_Number 1N4448WX-TP; Digikey Part Number 1N4448WXTPMSCT-ND
Q1, Q2, Q3, Q4: ISL9V5036P3-F085; TO254P470X1016X2019-3P; Manufacturer_Part_Number ISL9V5036P3-F085; Mouser Part Number 512-ISL9V5036P3-F085
R27, R31, R32, R33, R34, R35: 10k; R_0805_2012Metric; Manufacturer_Part_Number RC0805FR-0710KL; Digikey Part Number 311-10.0KCRCT-ND
R28, R29, R53, R54: 33; R_0805_2012Metric; Manufacturer_Part_Number RC0805FR-7W33RL; Digikey Part Number 13-RC0805FR-7W33RLCT-ND
R30: 20m; R_2512_6332Metric; Manufacturer_Part_Number WSL2512R0200FEA; Digikey Part Number WSLG-.02CT-ND
R36, R37, R38, R39, R42, R43, R44, R45: 18k; R_1206_3216Metric; Manufacturer_Part_Number RC1206FR-0718KL; Digikey Part Number 311-18.0KFRCT-ND
R40, R41, R51, R52: 1k; R_0805_2012Metric; Manufacturer_Part_Number RC0805FR-071KL; Digikey Part Number 311-1.00KCRCT-ND
R46, R47, R48, R49: 4.02k; R_0805_2012Metric; Manufacturer_Part_Number RC0805FR-074K02L; Digikey Part Number 311-4.02KCRCT-ND
R50: 100k; R_0805_2012Metric; Manufacturer_Part_Number RC0805FR-07100KL; Digikey Part Number 311-100KCRCT-ND
U7: MC33810; SOIC32-P0.65-33N; Manufacturer_Part_Number MCZ33810EK; Digikey Part Number MCZ33810EK-ND
U8: TPS3823-33DBV; SOT-23-5; Manufacturer_Part_Number TPS3823-33DBVR; Digikey Part Number 296-1357-1-ND
U9: 74LVC1G00; SOT-353_SC-70-5; Manufacturer_Part_Number SN74LVC1G00DCKR; Digikey Part Number 296-9846-1-ND

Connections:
12V-PROT: C17.1, C18.1, R40.2, R41.1, R51.2, R52.2, U7.25 (VPWR); also elsewhere on the board
+3V3: C15.2, C16.1, C19.1, C20.1, R27.2, R35.2, U7.8 (VDD), U8.3 (~MR), U8.5 (VDD), U9.5 (VCC); also elsewhere on the board
/Drivers/FB0: R42.2, R46.1, U7.2 (FB0)
/Drivers/FB1: R43.2, R47.1, U7.15 (FB1)
/Drivers/FB2: R44.2, R48.1, U7.31 (FB2)
/Drivers/FB3: R45.2, R49.1, U7.18 (FB3)
/Drivers/G_IGN1: Q2.1, R29.1, R31.1
/Drivers/G_IGN2: Q1.1, R28.1, R32.1
/Drivers/G_IGN3: Q3.1, R33.1, R53.1
/Drivers/G_IGN4: Q4.1, R34.1, R54.1
/Drivers/IGBT_E: Q1.3, Q2.3, Q3.3, Q4.3, R30.1, R31.2, R32.2, R33.2, R34.2, U7.26 (RSP)
/Drivers/WDT-RESET: U8.1 (~RESET), U9.2 (B)
GND: C15.1, C16.2, C17.2, C18.2, C19.2, C20.2, R50.2, U8.2 (GND), U9.3 (GND); also elsewhere on the board
IGN1: Q2.2, R36.1; also elsewhere on the board
IGN2: Q1.2, R37.1; also elsewhere on the board
IGN3: Q3.2, R38.1; also elsewhere on the board
IGN4: Q4.2, R39.1; also elsewhere on the board
INJ1: D11.1 (K), U7.1 (OUT0); also elsewhere on the board
INJ2: D10.1 (K), U7.16 (OUT1); also elsewhere on the board
INJ3: D13.1 (K), U7.32 (OUT2); also elsewhere on the board
INJ4: D12.1 (K), U7.17 (OUT3); also elsewhere on the board
MC33810_1-CS: R27.1, U7.4 (CS); also elsewhere on the board
MCU-D2: R50.1, U9.1 (A); also elsewhere on the board
MCU-D3: U8.4 (WDI); also elsewhere on the board
MISO: U7.7 (SO); also elsewhere on the board
MOSI: U7.6 (SI); also elsewhere on the board
unnamed: D8.2 (A), R40.1
unnamed: D9.2 (A), R41.2
unnamed: D8.1 (K), D10.2 (A)
unnamed: D9.1 (K), D11.2 (A)
unnamed: D12.2 (A), D14.1 (K)
unnamed: D13.2 (A), D15.1 (K)
unnamed: D14.2 (A), R51.1
unnamed: D15.2 (A), R52.1
unnamed: R36.2, R42.1
unnamed: R37.2, R43.1
unnamed: R38.2, R44.1
unnamed: R39.2, R45.1
OUTEN_1: R35.1, U7.9 (OUTEN), U9.4 (Y)
PGND: R30.2, R46.2, R47.2, R48.2, R49.2, U7.27 (RSN), U7.33 (GND); also elsewhere on the board
SCLK: U7.5 (SCLK); also elsewhere on the board
T_IGN1: R29.2, U7.3 (GD0)
T_IGN2: R28.2, U7.14 (GD1)
T_IGN3: R53.2, U7.30 (GD2)
T_IGN4: R54.2, U7.19 (GD3)

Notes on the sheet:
Zuendstrom-Shunt: alle IGBT-Emitter -> 20mOhm -> PGND
OUTEN-Safety: OUTEN aktiv LOW, R16 Pull-Up +3V3 (Boot=AUS).
RSP=IGBT_E, RSN=PGND (Kelvin-Layout!), Schwellen per SPI-DAC, Gain=2
Brownout/MCU-Absturz -> RESET low -> NAND=HIGH -> alle 8 Endstufen aus.
TC4424/SW3/F1/IGN_V+ entfallen. VPWR/Freilauf an 12V-PROT. U7-GND = PGND (Injektor-Rueckstrom).
Rev 3.0: MC33810 GD0-3 (5-9V Ladungspumpe) -> 33R -> ISL9V5036 direkt.
Freigabe nur bei MCU-D2=HIGH UND Watchdog-RESET=HIGH (WDI<1.6s von MCU-D3).
*Note: Max current per injector channel is 3.5A

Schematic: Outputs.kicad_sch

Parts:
C44, C45: 10n; C_0805_2012Metric; Manufacturer_Part_Number CC0805KRX7R9BB103; Digikey Part Number 311-1136-1-ND
C46: 100u/50V; CP_Elec_8x10; Manufacturer_Part_Number EEE-FK1H101GP; Digikey Part Number PCE4323CT-ND
C47: 1u; C_0805_2012Metric; Manufacturer_Part_Number CC0805KKX7R7BB105; Digikey Part Number 311-1365-1-ND
C48: 220n; C_0805_2012Metric; Manufacturer_Part_Number CC0805KKX7R9BB224; Digikey Part Number 311-1887-1-ND
C49: 22n; C_0805_2012Metric; Manufacturer_Part_Number CC0805KRX7R9BB223; Digikey Part Number 311-1138-1-ND
C50: 1n; C_0805_2012Metric; Manufacturer_Part_Number C0805C102J5HACAUTO; Digikey Part Number 399-16591-1-ND
C51, C52: 100n; C_0805_2012Metric; Manufacturer_Part_Number CC0805KRX7R9BB104; Digikey Part Number 311-1140-1-ND
D31, D32, D33, D34, D35, D36, D39, D40: SS34; D_SMA; Manufacturer_Part_Number B340A-13-F; Digikey Part Number B340A-FDICT-ND
D37, D38: 1N4148W; D_SOD-123; Manufacturer_Part_Number 1N4148W-7-F; Digikey Part Number 1N4148W-FDICT-ND
IC2, IC3, IC4: ZXMS6006DT8; SOT153P700X170-8N; Manufacturer_Part_Number ZXMS6006DT8TA; Digikey Part Number ZXMS6006DT8TADICT-ND
Q5: BSS138; SOT-23; Manufacturer_Part_Number BSS138; Digikey Part Number BSS138CT-ND
R93, R94, R95, R96, R97, R98: 1k; R_0805_2012Metric; Manufacturer_Part_Number RC0805FR-071KL; Digikey Part Number 311-1.00KCRCT-ND
R99, R100, R101, R102, R103, R104, R108, R109, R112: 100k; R_0805_2012Metric; Manufacturer_Part_Number RC0805FR-07100KL; Digikey Part Number 311-100KCRCT-ND
R105: 15k; R_0805_2012Metric; Manufacturer_Part_Number RC0805FR-0715KL; Digikey Part Number 311-15.0KCRCT-ND
R106, R110, R111, R113: 10k; R_0805_2012Metric; Manufacturer_Part_Number RC0805FR-0710KL; Digikey Part Number 311-10.0KCRCT-ND
R107: 330k; R_0805_2012Metric; Manufacturer_Part_Number RC0805FR-07330KL; Digikey Part Number 311-330KCRCT-ND
U12: DRV8434A; HTSSOP-28-1EP_4.4x9.7mm_P0.65mm_EP2.85x5.4mm_ThermalVias; Manufacturer_Part_Number DRV8434APWPR; Digikey Part Number 296-DRV8434APWPRCT-ND
U13, U14: BTF3050TE; TO-252-5_TabPin3; Manufacturer_Part_Number BTF3050TEATMA1; Digikey Part Number BTF3050TEATMA1CT-ND

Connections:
12V-PROT: C44.1, C45.1, C46.1, C48.1, D31.1 (K), D32.1 (K), D33.1 (K), D34.1 (K), D35.1 (K), D36.1 (K), D39.1 (K), D40.1 (K), U12.2 (VM), U12.13 (VM); also elsewhere on the board
+3V3: C51.1, C52.1, R113.1, U12.18 (M0), U12.22 (M1), U13.2 (VDD), U14.2 (VDD); also elsewhere on the board
/Outputs/DRV_DVDD: C47.1, R105.1, U12.15 (DVDD)
/Outputs/DRV_STLM: R107.1, U12.21 (STL_MODE)
/Outputs/DRV_TRQ: C50.1, U12.20 (TRQ_CNT/STL_TH)
/Outputs/DRV_VREF: R105.2, R106.1, U12.17 (VREF)
/Outputs/G_FAN: IC4.1 (INPUT_1), R97.2, R103.1
/Outputs/G_FI: IC2.1 (INPUT_1), R93.2, R99.1
/Outputs/G_FUEL: IC3.1 (INPUT_1), R95.2, R101.1
/Outputs/G_SPARE: IC4.3 (INPUT_2), R98.2, R104.1
/Outputs/G_STRT: IC2.3 (INPUT_2), R94.2, R100.1
/Outputs/G_TACH: IC3.3 (INPUT_2), R96.2, R102.1
/Outputs/OUT-FAULT-H: D37.1 (K), D38.1 (K), Q5.1 (G), R112.1
/Outputs/SRP_BOOST: D37.2 (A), R110.1, U13.4 (SRP)
/Outputs/SRP_O2: D38.2 (A), R111.1, U14.4 (SRP)
BOOST-OUT: D39.2 (A), U13.3 (OUT); also elsewhere on the board
FAN-OUT: D35.2 (A), IC4.7 (DRAIN_1_1), IC4.8 (DRAIN_1_2); also elsewhere on the board
FI-LAMP: D31.2 (A), IC2.7 (DRAIN_1_1), IC2.8 (DRAIN_1_2); also elsewhere on the board
FUELPUMP-OUT: D33.2 (A), IC3.7 (DRAIN_1_1), IC3.8 (DRAIN_1_2); also elsewhere on the board
GND: C47.2, C50.2, C51.2, C52.2, Q5.3 (S), R99.2, R100.2, R101.2, R102.2, R103.2, R104.2, R106.2, R107.2, R108.1, R109.1, R110.2, R111.2, R112.2, U12.14 (GND), U12.29 (PAD); also elsewhere on the board
MCU-D5: R95.1; also elsewhere on the board
MCU-D8: R96.1; also elsewhere on the board
MCU-D9: Q5.2 (D), R113.2, U12.16 (nFAULT); also elsewhere on the board
MCU-D24: R108.2, U13.1 (IN); also elsewhere on the board
MCU-D25: R109.2, U14.1 (IN); also elsewhere on the board
MCU-D26: R94.1; also elsewhere on the board
MCU-D27: R93.1; also elsewhere on the board
MCU-D28: R98.1; also elsewhere on the board
MCU-D29: R97.1; also elsewhere on the board
MCU-D30: U12.23 (STEP); also elsewhere on the board
MCU-D31: U12.24 (DIR); also elsewhere on the board
MCU-D32: U12.25 (ENABLE), U12.26 (nSLEEP); also elsewhere on the board
unnamed: C49.2, U12.28 (CPH)
unnamed: C49.1, U12.27 (CPL)
unnamed: C48.2, U12.1 (VCP)
O2-HEATER: D40.2 (A), U14.3 (OUT); also elsewhere on the board
PGND: C44.2, C45.2, C46.2, IC2.2 (SOURCE_1), IC2.4 (SOURCE_2), IC3.2 (SOURCE_1), IC3.4 (SOURCE_2), IC4.2 (SOURCE_1), IC4.4 (SOURCE_2), U12.3 (PGND), U12.12 (PGND), U13.5 (GND), U14.5 (GND); also elsewhere on the board
SPARE-OUT: D36.2 (A), IC4.5 (DRAIN_2_1), IC4.6 (DRAIN_2_2); also elsewhere on the board
STARTER-OUT: D32.2 (A), IC2.5 (DRAIN_2_1), IC2.6 (DRAIN_2_2); also elsewhere on the board
STEPPER-A1: U12.4 (AOUT1), U12.5 (AOUT1); also elsewhere on the board
STEPPER-A2: U12.6 (AOUT2), U12.7 (AOUT2); also elsewhere on the board
STEPPER-B1: U12.10 (BOUT1), U12.11 (BOUT1); also elsewhere on the board
STEPPER-B2: U12.8 (BOUT2), U12.9 (BOUT2); also elsewhere on the board
TACHO-OUT: D34.2 (A), IC3.5 (DRAIN_2_1), IC3.6 (DRAIN_2_2); also elsewhere on the board

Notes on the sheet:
D) Status-ODER: SRP high (Übertemperatur-Latch) → Diode → OUT-FAULT-H → BSS138 zieht MCU-D9 (nFAULT, wired-OR) auf low
C) BTF3050TE Smart-Low-Side (VDD=+3V3 → Status 3V3-sicher; R_SRP 10k = Slew/Status; Freilauf SS34 nach 12V-PROT)
B) ZXMS6006DT8 Dual-Low-Side — IC2: FI-Lampe / Starter-Relais, IC3: Kraftstoffpumpe / Tacho, IC4: Lüfter / Spare
DRV8434A Peripherie
A) Gate-Netzwerke: MCU-Pin → 1k → Gate, 100k Pulldown (Boot-sicher aus)
E) DRV8434A Stepper (VM=12V-PROT, 1/8-Schritt, IFS = VREF/1.32 V/A = 1.0 A @ VREF 1.32 V, Stall-Erkennung aus, nFAULT → MCU-D9)

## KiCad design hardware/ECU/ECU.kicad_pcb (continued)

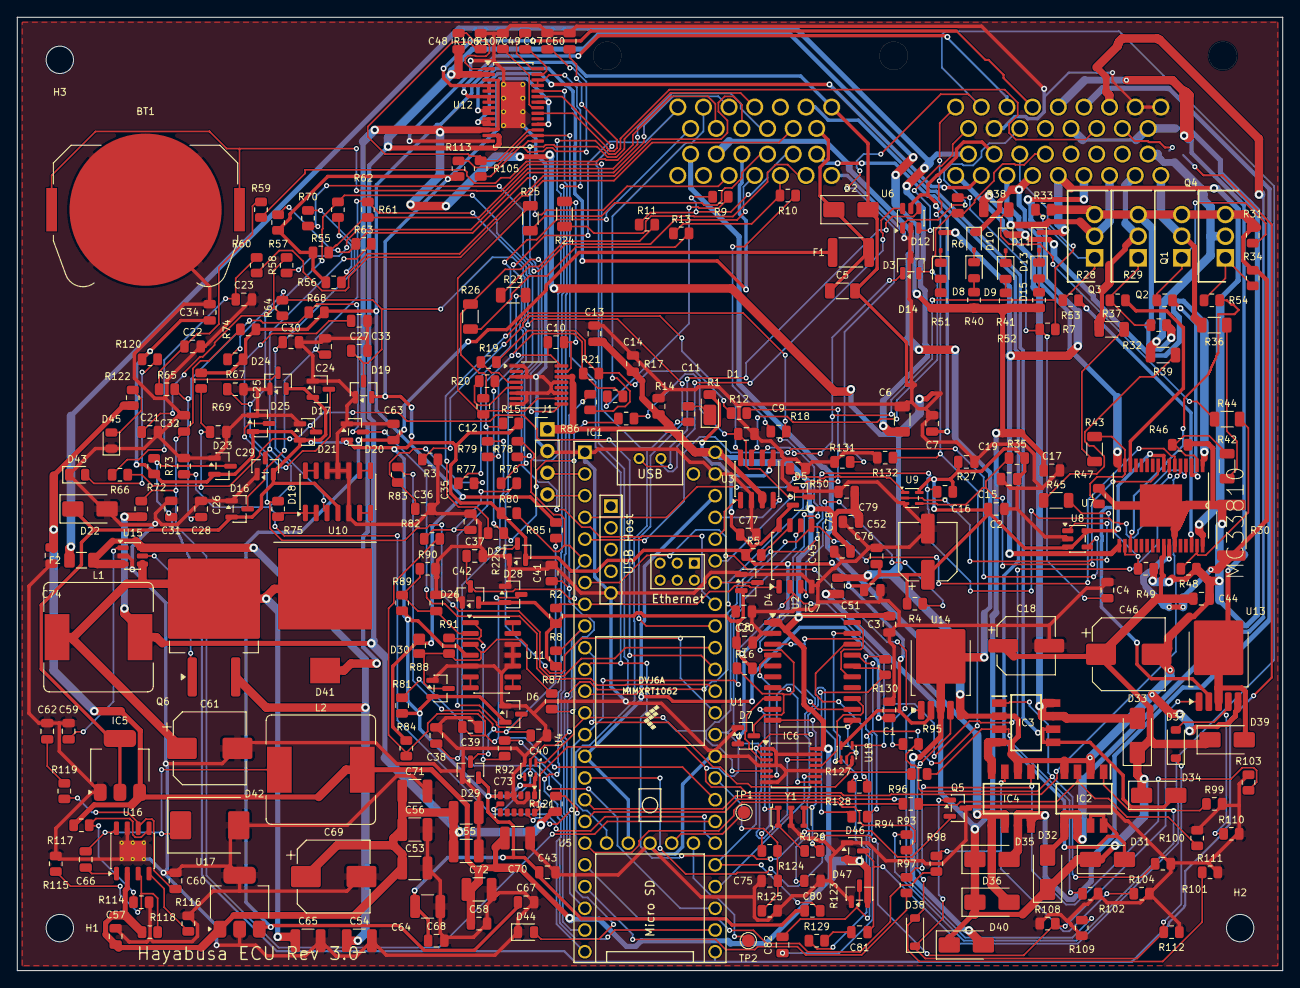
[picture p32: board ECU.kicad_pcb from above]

Board: 2 copper layers, 148.0 x 111.5 mm, 307 parts (1 on the bottom side), 211 nets.

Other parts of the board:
H1, H2, H3: M3; MountingHole_3.2mm_M3

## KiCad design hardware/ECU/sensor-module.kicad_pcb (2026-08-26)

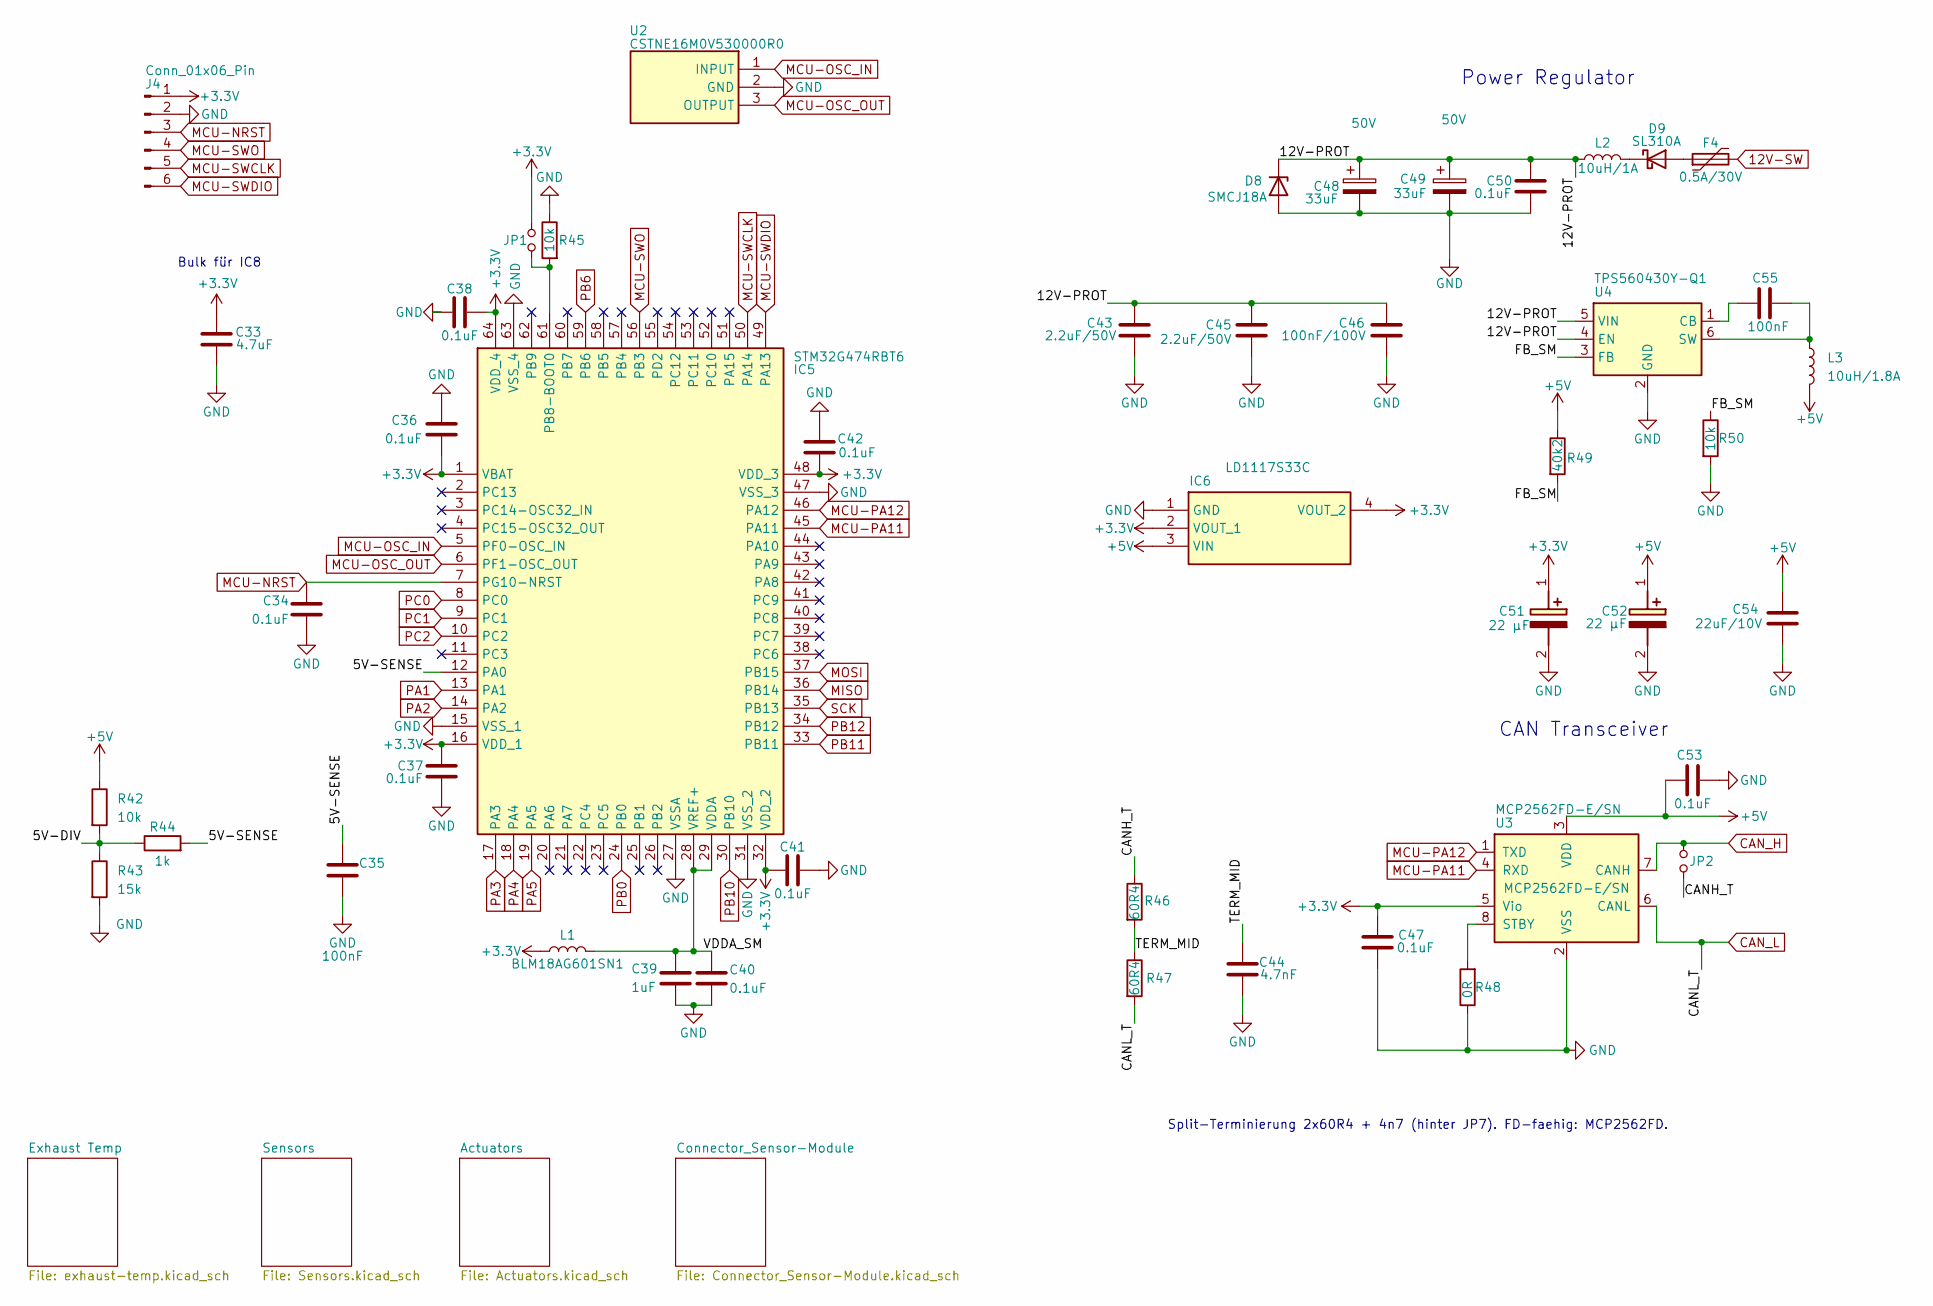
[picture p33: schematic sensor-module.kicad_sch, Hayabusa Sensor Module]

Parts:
C33: 4.7uF; C_0805_2012Metric; Manufacturer_Part_Number CC0805KKX7R7BB475; Digikey Part Number 311-1883-1-ND
C34, C36, C37, C38, C40, C41, C42, C47, C50, C53: 0.1uF; C_0805_2012Metric; Manufacturer_Part_Number CC0805KRX7R9BB104; Digikey Part Number 311-1140-1-ND
C35, C55: 100nF; C_0805_2012Metric; Manufacturer_Part_Number CC0805KRX7R9BB104; Digikey Part Number 311-1140-1-ND
C39: 1uF; C_0805_2012Metric; Manufacturer_Part_Number CC0805KKX7R7BB105; Digikey Part Number 311-1365-1-ND
C43, C45: 2.2uF/50V; C_1210_3225Metric; Manufacturer_Part_Number C3225X7R1H225K250AB; Digikey Part Number 445-1431-1-ND
C44: 4.7nF; C_0805_2012Metric; Manufacturer_Part_Number CC0805KRX7R9BB472; Digikey Part Number 311-1133-1-ND
C46: 100nF/100V; C_0805_2012Metric; Manufacturer_Part_Number C0805C104K1RACTU; Digikey Part Number 399-C0805C104K1RACTUCT-ND
C48, C49: 33uF; CP_Elec_6.3x7.7; Voltage 50V; Manufacturer_Part_Number EEE-1HA330XP; Digikey Part Number PCE3925CT-ND
C51, C52: 22 µF; EEE1AA221P; Manufacturer_Part_Number EEE-FK1H220P; Digikey Part Number PCE3811CT-ND
C54: 22uF/10V; C_1210_3225Metric; Manufacturer_Part_Number GRM32ER71A226KE20L; Digikey Part Number 490-1876-1-ND
D8: SMCJ18A; D_SMC; Manufacturer_Part_Number SMCJ18A; Digikey Part Number SMCJ18ALFCT-ND
D9: SL310A; D_SMA_Handsoldering; Manufacturer_Part_Number SL310A-TP; Digikey Part Number SL310A-TPMSCT-ND
F4: 0.5A/30V; Fuse_1812_4532Metric; Manufacturer_Part_Number 1812L050/60MR; Digikey Part Number F8132CT-ND
IC5: STM32G474RBT6; QFP50P1200X1200X160-64N; Manufacturer_Part_Number STM32G474RBT6; Mouser Part Number 511-STM32G474RBT6
IC6: LD1117S33C; Manufacturer_Part_Number LD1117S33CTR; Mouser Part Number N/A
J4: Conn_01x06_Pin; PinHeader_1x06_P2.54mm_Vertical; Manufacturer_Part_Number 61300611121; Digikey Part Number 732-5319-ND
JP1, JP2: Jumper_NO_Small; SolderJumper-2_P1.3mm_Open_Pad1.0x1.5mm
L1: BLM18AG601SN1; L_0603_1608Metric; Manufacturer_Part_Number BLM18AG601SN1D; Digikey Part Number 490-1014-1-ND
L2: 10uH/1A; L_1210_3225Metric; Manufacturer_Part_Number LQH32PN100MNCL; Digikey Part Number 490-LQH32PN100MNCLCT-ND
L3: 10uH/1.8A; L_Bourns_SRN6045TA; Part Nr SRN6045; Digikey Part Number SRN6045TA-100MCT-ND
R42, R50: 10k; R_0805_2012Metric; Manufacturer_Part_Number RC0805FR-0710KL; Digikey Part Number 311-10.0KCRCT-ND
R43: 15k; R_0805_2012Metric; Manufacturer_Part_Number RC0805FR-0715KL; Digikey Part Number 311-15.0KCRCT-ND
R44: 1k; R_0805_2012Metric; Manufacturer_Part_Number RC0805FR-071KL; Digikey Part Number 311-1.00KCRCT-ND
R45: 10k; R_0805_2012Metric; Manufacturer_Part_Number RC0805JR-0710KL; Digikey Part Number 311-10KARCT-ND
R46, R47: 60R4; R_0805_2012Metric; Manufacturer_Part_Number RC0805FR-0760R4L; Digikey Part Number 311-60.4CRCT-ND
R48: 0R; R_0805_2012Metric; Manufacturer_Part_Number RC0805JR-070RL; Digikey Part Number 311-0.0ARCT-ND
R49: 40k2; R_0805_2012Metric; Manufacturer_Part_Number RC0805FR-0740K2L; Digikey Part Number 311-40.2KCRCT-ND
U2: CSTNE16M0V530000R0; Manufacturer_Part_Number CSTNE16M0V530000R0; Mouser Part Number 81-CSTNE16M0V530000R
U3: MCP2562FD-E/SN; SOIC-8_3.9x4.9mm_P1.27mm; Manufacturer_Part_Number MCP2562FD-E/SN; Digikey Part Number MCP2562FD-E/SN-ND
U4: TPS560430Y-Q1; SOT-23-6; Manufacturer_Part_Number TPS560430YQDBVRQ1; Digikey Part Number 296-TPS560430YQDBVRQ1CT-ND

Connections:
12V-SW: F4.2; also elsewhere on the board
+3.3V: C33.1, C36.1, C37.1, C38.1, C41.1, C42.2, C47.1, C51.1 (+), IC5.1 (VBAT), IC5.16 (VDD_1), IC5.32 (VDD_2), IC5.48 (VDD_3), IC5.64 (VDD_4), IC6.2 (VOUT_1), IC6.4 (VOUT_2), J4.1, JP1.1, L1.1, U3.5 (Vio); also elsewhere on the board
+5V: C52.1 (+), C53.1, C54.1, IC6.3 (VIN), L3.2, R42.1, R49.1, U3.3 (VDD); also elsewhere on the board
/5V-DIV: R42.2, R43.1, R44.1
/5V-SENSE: C35.1, IC5.12 (PA0), R44.2
/12V-PROT: C43.1, C45.1, C46.1, C48.1, C49.1, C50.1, D8.1 (K), L2.1, U4.4 (EN), U4.5 (VIN)
/CANH_T: JP2.2, R46.1
/FB_SM: R49.2, R50.1, U4.3 (FB)
/TERM_MID: C44.1, R46.2, R47.1
/VDDA_SM: C39.1, C40.1, IC5.28 (VREF+), IC5.29 (VDDA), L1.2
ADC-Clamp-1: IC5.8 (PC0); also elsewhere on the board
ADC-Clamp-2: IC5.10 (PC2); also elsewhere on the board
ADC-Clamp-3: IC5.18 (PA4); also elsewhere on the board
ADC-Clamp-4: IC5.9 (PC1); also elsewhere on the board
ADC-Clamp-5: IC5.17 (PA3); also elsewhere on the board
ADC-Clamp-6: IC5.19 (PA5); also elsewhere on the board
ADC-Clamp-7: IC5.13 (PA1); also elsewhere on the board
ADC-Clamp-8: IC5.14 (PA2); also elsewhere on the board
CAN_H: JP2.1, U3.7 (CANH); also elsewhere on the board
CAN_L: R47.2, U3.6 (CANL); also elsewhere on the board
GND: C33.2, C34.2, C35.2, C36.2, C37.2, C38.2, C39.2, C40.2, C41.2, C42.1, C43.2, C44.2, C45.2, C46.2, C47.2, C48.2, C49.2, C50.2, C51.2 (-), C52.2 (-), C53.2, C54.2, D8.2 (A), IC5.15 (VSS_1), IC5.27 (VSSA), IC5.31 (VSS_2), IC5.47 (VSS_3), IC5.63 (VSS_4), IC6.1 (GND), J4.2, R43.2, R45.1, R48.1, R50.2, U2.2 (GND), U3.2 (VSS), U4.2 (GND); also elsewhere on the board
MCU-NRST: C34.1, IC5.7 (PG10-NRST), J4.3
MCU-OSC_IN: IC5.5 (PF0-OSC_IN), U2.1 (INPUT)
MCU-OSC_OUT: IC5.6 (PF1-OSC_OUT), U2.3 (OUTPUT)
MCU-PA11: IC5.45 (PA11), U3.4 (RXD)
MCU-PA12: IC5.46 (PA12), U3.1 (TXD)
MCU-SWCLK: IC5.50 (PA14), J4.5
MCU-SWDIO: IC5.49 (PA13), J4.6
MCU-SWO: IC5.56 (PB3), J4.4
MISO: IC5.36 (PB14); also elsewhere on the board
MOSI: IC5.37 (PB15)
unnamed: D9.2 (A), F4.1
unnamed: D9.1 (K), L2.2
unnamed: IC5.61 (PB8-BOOT0), JP1.2, R45.2
unnamed: R48.2, U3.8 (STBY)
unnamed: C55.1, U4.1 (CB)
unnamed: C55.2, L3.1, U4.6 (SW)
PB0: IC5.24 (PB0); also elsewhere on the board
PB6: IC5.59 (PB6); also elsewhere on the board
PB10: IC5.30 (PB10); also elsewhere on the board
PB11: IC5.33 (PB11); also elsewhere on the board
PB12: IC5.34 (PB12); also elsewhere on the board
SCK: IC5.35 (PB13); also elsewhere on the board

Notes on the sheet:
CAN Transceiver
Bulk für IC8
Split-Terminierung 2x60R4 + 4n7 (hinter JP7). FD-faehig: MCP2562FD.
Power Regulator

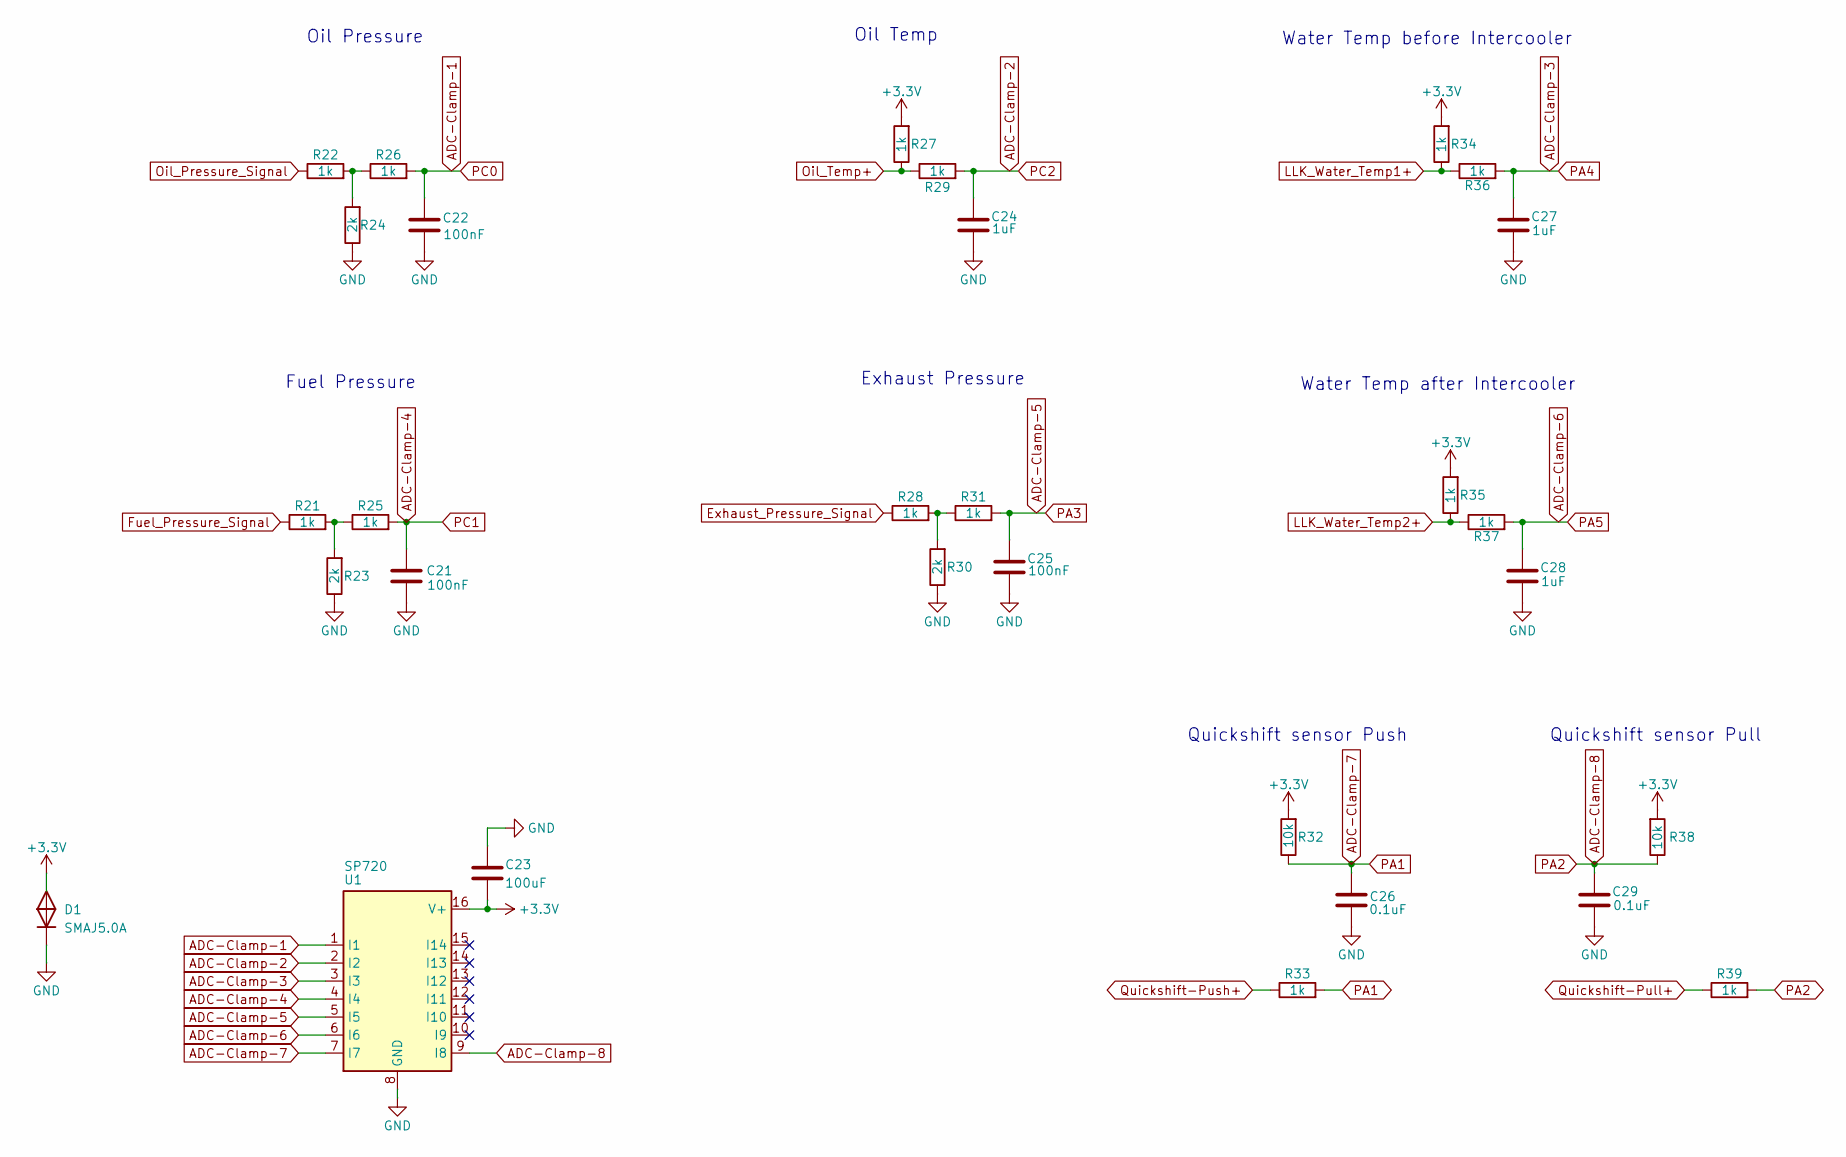
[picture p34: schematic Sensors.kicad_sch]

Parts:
C21, C22, C25: 100nF; C_0805_2012Metric; Manufacturer_Part_Number CC0805KRX7R9BB104; Digikey Part Number 311-1140-1-ND
C23: 100uF; C_1206_3216Metric; Manufacturer_Part_Number CL31A107MQHNNNE; Digikey Part Number 1276-1782-1-ND
C24, C27, C28: 1uF; C_0805_2012Metric; Manufacturer_Part_Number CC0805KKX7R7BB105; Digikey Part Number 311-1365-1-ND
C26, C29: 0.1uF; C_0805_2012Metric; Manufacturer_Part_Number CC0805KRX7R9BB104; Digikey Part Number 311-1140-1-ND
D1: SMAJ5.0A; D_SMA; Manufacturer_Part_Number SMAJ5.0A; Digikey Part Number SMAJ5.0ALFCT-ND
R21, R22, R25, R26, R27, R28, R29, R31, R33, R34, R35, R36, R37, R39: 1k; R_0805_2012Metric; Manufacturer_Part_Number RC0805FR-071KL; Digikey Part Number 311-1.00KCRCT-ND
R23, R24, R30: 2k; RESC2012X60N; Manufacturer_Part_Number RC0805FR-072KL; Mouser Part Number 603-RC0805FR-072KL
R32, R38: 10k; R_1206_3216Metric; Manufacturer_Part_Number RC1206FR-7W10KL; Digikey Part Number 13-RC1206FR-7W10KLTR-ND
U1: SP720; SOIC-16_3.9x9.9mm_P1.27mm; Manufacturer_Part_Number SP720ABTG; Digikey Part Number F3162CT-ND

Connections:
+3.3V: C23.2, D1.1, R27.2, R32.2, R34.2, R35.2, R38.2, U1.16 (V+); also elsewhere on the board
ADC-Clamp-1: C22.1, R26.2, U1.1 (I1); also elsewhere on the board
ADC-Clamp-2: C24.1, R29.2, U1.2 (I2); also elsewhere on the board
ADC-Clamp-3: C27.1, R36.2, U1.3 (I3); also elsewhere on the board
ADC-Clamp-4: C21.1, R25.2, U1.4 (I4); also elsewhere on the board
ADC-Clamp-5: C25.1, R31.2, U1.5 (I5); also elsewhere on the board
ADC-Clamp-6: C28.1, R37.2, U1.6 (I6); also elsewhere on the board
ADC-Clamp-7: C26.2, R32.1, R33.2, U1.7 (I7); also elsewhere on the board
ADC-Clamp-8: C29.2, R38.1, R39.2, U1.9 (I8); also elsewhere on the board
Exhaust_Pressure_Signal: R28.1; also elsewhere on the board
Fuel_Pressure_Signal: R21.1; also elsewhere on the board
GND: C21.2, C22.2, C23.1, C24.2, C25.2, C26.1, C27.2, C28.2, C29.1, D1.2, R23.1, R24.1, R30.1, U1.8 (GND); also elsewhere on the board
LLK_Water_Temp1+: R34.1, R36.1; also elsewhere on the board
LLK_Water_Temp2+: R35.1, R37.1; also elsewhere on the board
unnamed: R21.2, R23.2, R25.1
unnamed: R22.2, R24.2, R26.1
unnamed: R28.2, R30.2, R31.1
Oil_Pressure_Signal: R22.1; also elsewhere on the board
Oil_Temp+: R27.1, R29.1; also elsewhere on the board
Quickshift-Pull+: R39.1; also elsewhere on the board
Quickshift-Push+: R33.1; also elsewhere on the board

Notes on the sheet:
Oil Pressure
Quickshift sensor Pull
Water Temp after Intercooler
Oil Temp
Water Temp before Intercooler
Quickshift sensor Push
Fuel Pressure
Exhaust Pressure

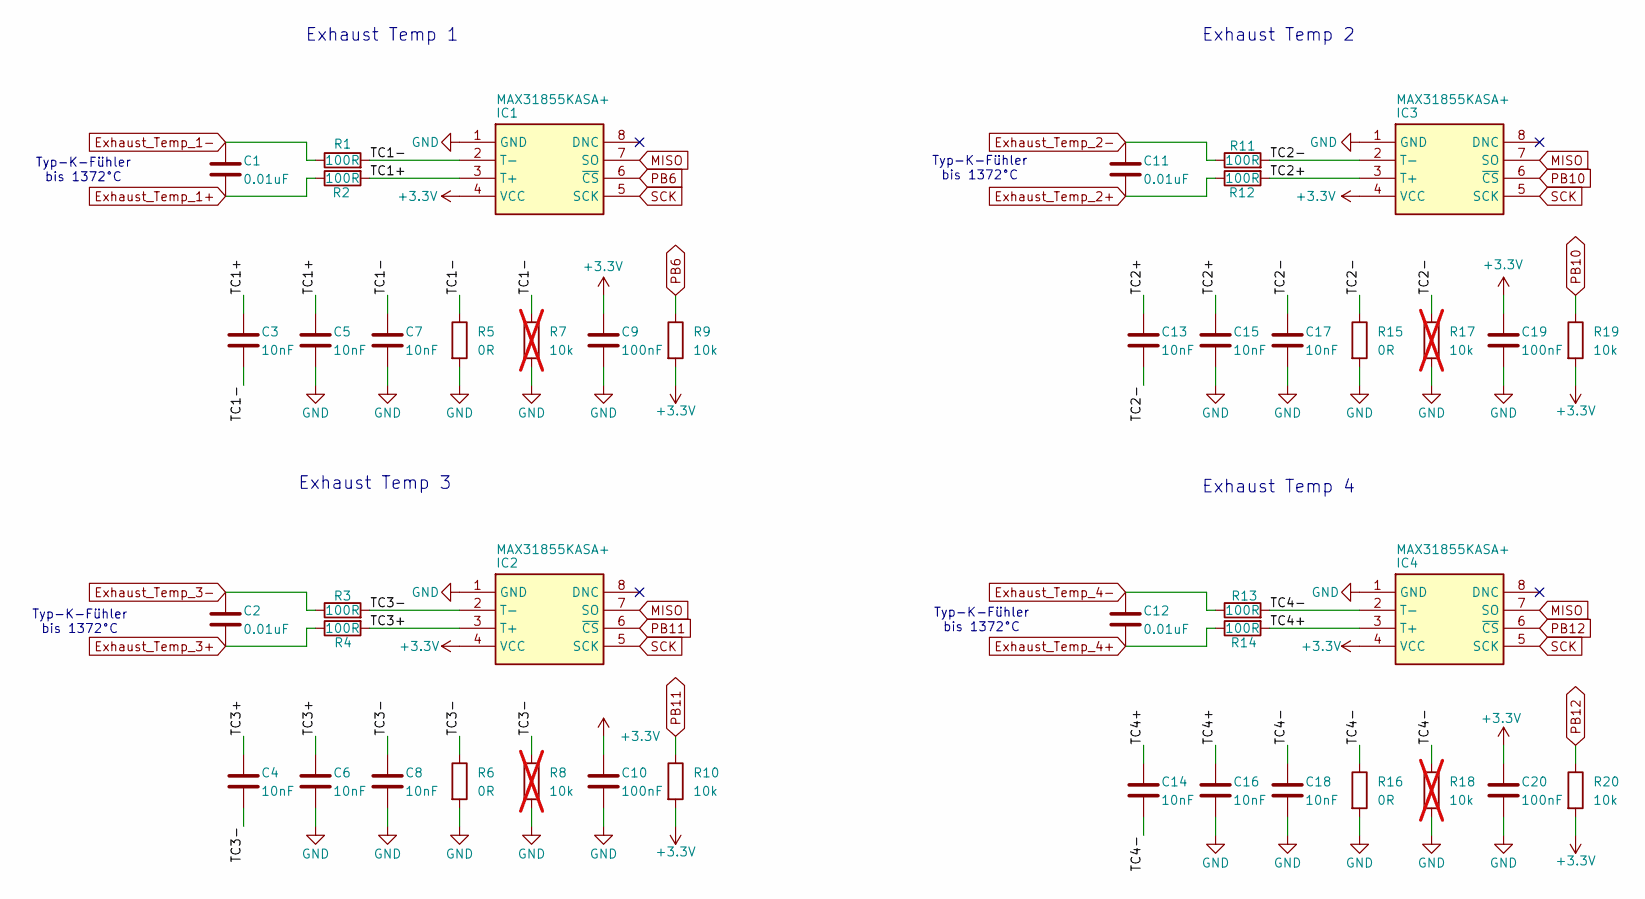
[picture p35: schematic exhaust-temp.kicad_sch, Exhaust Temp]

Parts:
C1, C2, C11, C12: 0.01uF; C_0805_2012Metric; Manufacturer_Part_Number CC0805KRX7R9BB103; Digikey Part Number 311-1136-1-ND
C3, C4, C5, C6, C7, C8, C13, C14, C15, C16, C17, C18: 10nF; C_0805_2012Metric; Manufacturer_Part_Number CC0805KRX7R9BB103; Digikey Part Number 311-1136-1-ND
C9, C10, C19, C20: 100nF; C_0805_2012Metric; Manufacturer_Part_Number CC0805KRX7R9BB104; Digikey Part Number 311-1140-1-ND
IC1, IC2, IC3, IC4: MAX31855KASA+; SOIC127P600X175-8N; Manufacturer_Part_Number MAX31855KASA+T; Mouser Part Number 700-MAX31855KASA+
R1, R2, R3, R4, R11, R12, R13, R14: 100R; ERJ6ENF1000V; Manufacturer_Part_Number ERJ-6ENF1000V; Digikey Part Number P100CCT-ND
R5, R6, R15, R16: 0R; R_0805_2012Metric; Manufacturer_Part_Number RC0805JR-070RL; Digikey Part Number 311-0.0ARCT-ND
R7, R8, R17, R18: 10k; R_0805_2012Metric; Manufacturer_Part_Number RC0805FR-0710KL; Digikey Part Number 311-10.0KCRCT-ND; not fitted
R9, R10, R19, R20: 10k; R_0805_2012Metric; Manufacturer_Part_Number RC0805FR-0710KL; Digikey Part Number 311-10.0KCRCT-ND

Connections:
+3.3V: C9.1, C10.1, C19.1, C20.1, IC1.4 (VCC), IC2.4 (VCC), IC3.4 (VCC), IC4.4 (VCC), R9.2, R10.2, R19.2, R20.2; also elsewhere on the board
/Exhaust Temp/TC1+: C3.1, C5.1, IC1.3 (T+), R2.2
/Exhaust Temp/TC1-: C3.2, C7.1, IC1.2 (T-), R1.2, R5.1, R7.1
/Exhaust Temp/TC2+: C13.1, C15.1, IC3.3 (T+), R12.2
/Exhaust Temp/TC2-: C13.2, C17.1, IC3.2 (T-), R11.2, R15.1, R17.1
/Exhaust Temp/TC3+: C4.1, C6.1, IC2.3 (T+), R4.2
/Exhaust Temp/TC3-: C4.2, C8.1, IC2.2 (T-), R3.2, R6.1, R8.1
/Exhaust Temp/TC4+: C14.1, C16.1, IC4.3 (T+), R14.2
/Exhaust Temp/TC4-: C14.2, C18.1, IC4.2 (T-), R13.2, R16.1, R18.1
Exhaust_Temp_1+: C1.2, R2.1; also elsewhere on the board
Exhaust_Temp_1-: C1.1, R1.1; also elsewhere on the board
Exhaust_Temp_2+: C11.2, R12.1; also elsewhere on the board
Exhaust_Temp_2-: C11.1, R11.1; also elsewhere on the board
Exhaust_Temp_3+: C2.2, R4.1; also elsewhere on the board
Exhaust_Temp_3-: C2.1, R3.1; also elsewhere on the board
Exhaust_Temp_4+: C12.2, R14.1; also elsewhere on the board
Exhaust_Temp_4-: C12.1, R13.1; also elsewhere on the board
GND: C5.2, C6.2, C7.2, C8.2, C9.2, C10.2, C15.2, C16.2, C17.2, C18.2, C19.2, C20.2, IC1.1 (GND), IC2.1 (GND), IC3.1 (GND), IC4.1 (GND), R5.2, R6.2, R7.2, R8.2, R15.2, R16.2, R17.2, R18.2; also elsewhere on the board
MISO: IC1.7 (SO), IC2.7 (SO), IC3.7 (SO), IC4.7 (SO); also elsewhere on the board
PB6: IC1.6 (~CS), R9.1; also elsewhere on the board
PB10: IC3.6 (~CS), R19.1; also elsewhere on the board
PB11: IC2.6 (~CS), R10.1; also elsewhere on the board
PB12: IC4.6 (~CS), R20.1; also elsewhere on the board
SCK: IC1.5 (SCK), IC2.5 (SCK), IC3.5 (SCK), IC4.5 (SCK); also elsewhere on the board

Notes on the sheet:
Typ-K-Fühler bis 1372°C
Exhaust Temp 1
Exhaust Temp 4
Exhaust Temp 2
Typ-K-Fühler bis 1372°C
Exhaust Temp 3


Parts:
C30, C31, C32: 100nF; C_0805_2012Metric; Manufacturer_Part_Number CC0805KRX7R9BB104; Digikey Part Number 311-1140-1-ND
D4: NUP2105L; SOT-23; Manufacturer_Part_Number NUP2105LT1G; Digikey Part Number NUP2105LT1GOSCT-ND
D5, D6, D7: SMAJ5.0A; D_SMA; Manufacturer_Part_Number SMAJ5.0A; Digikey Part Number SMAJ5.0ALFCT-ND
F1, F2, F3: 50mA; Fuse_1206_3216Metric; Manufacturer_Part_Number 0ZCJ0005FF2E; Digikey Part Number 5923-0ZCJ0005FF2ECT-ND
J1, J2: MX23A12NF1; Mouser Part Number 656-MX23A12NF1
J3: 1-776266-1; 17762661; Manufacturer_Part_Number 1-776266-1; Mouser Part Number 571-1-776266-1

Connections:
12V-SW: J1.1, J3.13; also elsewhere on the board
+5V: F1.1, F2.1, F3.1; also elsewhere on the board
/Connector_Sensor-Module/+5V-EXT1: C31.1, D6.1, F2.2, J2.1
/Connector_Sensor-Module/+5V-EXT2: C32.1, D7.1, F3.2, J2.8
/Connector_Sensor-Module/+5V-EXT3: C30.1, D5.1, F1.2, J3.10
CAN_H: D4.2 (I/O2), J1.3; also elsewhere on the board
CAN_L: D4.1 (I/O1), J1.4; also elsewhere on the board
Exhaust_Pressure_Signal: J3.11; also elsewhere on the board
Exhaust_Temp_1+: J3.6; also elsewhere on the board
Exhaust_Temp_1-: J3.1; also elsewhere on the board
Exhaust_Temp_2+: J3.7; also elsewhere on the board
Exhaust_Temp_2-: J3.2; also elsewhere on the board
Exhaust_Temp_3+: J3.8; also elsewhere on the board
Exhaust_Temp_3-: J3.3; also elsewhere on the board
Exhaust_Temp_4+: J3.9; also elsewhere on the board
Exhaust_Temp_4-: J3.4; also elsewhere on the board
Fuel_Pressure_Signal: J2.3; also elsewhere on the board
GND: C30.2, C31.2, C32.2, D4.3 (GND), D5.2, D6.2, D7.2, J1.2, J1.9, J1.11, J2.2, J2.5, J2.7, J2.9, J2.12, J3.5; also elsewhere on the board
Intercooler-Fan-: J3.12; also elsewhere on the board
LLK_Water_Temp1+: J2.6; also elsewhere on the board
LLK_Water_Temp2+: J2.11; also elsewhere on the board
Oil_Pressure_Signal: J2.10; also elsewhere on the board
Oil_Temp+: J2.4; also elsewhere on the board
Quickshift-Pull+: J1.10; also elsewhere on the board
Quickshift-Push+: J1.8; also elsewhere on the board

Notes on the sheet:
Fuel_Pressure+
Exhaust_Pressure-
LLK_Water_Temp2-
Exhaust_Pressure+
Quickshift-Pull-
Oil_Temp-
Oil_Pressure+
Fuel_Pressure-
LLK_Water_Temp1-
Oil_Pressure-
Quickshift-Push-


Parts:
D2: SK510L; D_SMC; Manufacturer_Part_Number SK510L-TP; Digikey Part Number SK510L-TPMSCT-ND
D3: SMBJ33A; D_SMB; Manufacturer_Part_Number SMBJ33A; Digikey Part Number SMBJ33ALFCT-ND
Q1: SQM120N06-3M5L; TO-263-2; Manufacturer_Part_Number SQM120N06-3M5L_GE3; Mouser Part Number 942-IRLB8721PBF
R40: 10k; R_1206_3216Metric; Manufacturer_Part_Number RC1206FR-7W10KL; Digikey Part Number 13-RC1206FR-7W10KLTR-ND
R41: 100; ERJ6ENF1000V; Manufacturer_Part_Number ERJ-6ENF1000V; Digikey Part Number P100CCT-ND

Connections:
12V-SW: D2.1 (K); also elsewhere on the board
GND: D3.2, Q1.3 (S), R40.2; also elsewhere on the board
Intercooler-Fan-: D2.2 (A), D3.1, Q1.2 (D); also elsewhere on the board
unnamed: Q1.1 (G), R40.1, R41.1
PB0: R41.2; also elsewhere on the board

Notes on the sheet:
Intercooler Fan



Board: 2 copper layers, 120.0 x 64.0 mm, 138 parts (22 on the bottom side), 74 nets.

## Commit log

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2024-11-06 new file: Hardware/ECU/ECU-backups/ECU-2024-11-06_180755.zip new file: Hardware/ECU/ECU-backups/ECU-2024-11-06_185548.zip new file: Hardware/ECU/ECU-backups/ECU-2024-11-06_190414.zip new file: Hardwa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
    [ECU.kicad_sch]
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2024-11-07 new file: Hardware/ECU/ECU-backups/ECU-2024-11-08_000501.zip new file: Hardware/ECU/lib/teensy.pretty new file: tune/Hayabusa-R1/CurrentTune.msq new file: tune/Hayabusa-R1/DataLogs/SPD_0001.csv new f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
    [SPD_0001.csv]
2024-11-08 modified: .gitmodules modified: Hardware/ECU/Comms.kicad_sch modified: Hardware/ECU/ECU.kicad_pcb modified: Hardware/ECU/ECU.kicad_pro modified: Hardware/ECU/ECU.kicad_sch modified: Hardware/ECU/Inpu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
    [Comms.kicad_sch, ECU.kicad_pcb, ECU.kicad_sch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]
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2024-12-18 Aktualisiere Subprojekt-Commit und füge neue Bibliotheken sowie Anpassungen in der ECU-Konfiguration hinzu
    [Conntectors.kicad_sch]
2025-01-03 modified: Hardware/ECU/Conntectors.kicad_sch deleted: Hardware/ECU/ECU-backups/ECU-2024-10-31_195121.zip deleted: Hardware/ECU/ECU-backups/ECU-2024-10-31_200337.zip deleted: Hardware/ECU/ECU-backups/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
    [Conntectors.kicad_sch, ECU.kicad_sch]
2025-01-06 new file: Hardware/ECU/ECU-backups/ECU-2024-12-18_220608.zip new file: Hardware/ECU/ECU-backups/ECU-2024-12-30_215431.zip new file: Hardware/ECU/ECU-backups/ECU-2024-12-31_001349.zip new file: Hardwa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
    [Pinout.ods]
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2025-05-15 Add new footprint for TO-220AB MOSFET (IRFB4110PBF)
    - Created a new KiCad module for the TO254P483X1016X1994-3P footprint.
    - Included necessary graphical elements such as courtyard, fabrication, and silkscreen layers.
    - Defined pads for through-hole connections with appropriate dimensions and drill sizes.
    - Added a 3D model reference for the IRFB4110PBF component.
    [Drivers.kicad_sch, ECU.kicad_pcb]
2025-05-18 PCB v0.2
    leiterbahndicke updated
    Clutch input rework
    [Conntectors.kicad_sch, ECU.kicad_pcb, Inputs.kicad_sch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]
2025-05-19 modified: Hardware/ECU/Conntectors.kicad_sch deleted: Hardware/ECU/ECU-backups/ECU-2025-05-14_000421.zip deleted: Hardware/ECU/ECU-backups/ECU-2025-05-14_001426.zip deleted: Hardware/ECU/ECU-backups/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
    [Conntectors.kicad_sch, ECU.kicad_pcb, ECU.kicad_sch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]
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2025-05-27 modified: Hardware/ECU/Drivers.kicad_sch deleted: Hardware/ECU/ECU-backups/ECU-2025-05-15_143348.zip deleted: Hardware/ECU/ECU-backups/ECU-2025-05-15_144355.zip deleted: Hardware/ECU/ECU-backups/ECU-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
    [Drivers.kicad_sch, ECU.csv, ECU.kicad_pcb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]
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2025-05-27 renamed: Hardware/ECU/ECU-backups/ECU-2025-05-27_141528.zip -> Hardware/ECU/ECU-backups/ECU-2025-05-27_234640.zip renamed: Hardware/ECU/ECU-backups/ECU-2025-05-27_154948.zip -> Hardware/ECU/ECU-backu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
    [ECU.kicad_pcb, ECU.kicad_sch]
2025-05-28 deleted: Hardware/ECU/ECU-backups/ECU-2025-05-17_000435.zip deleted: Hardware/ECU/ECU-backups/ECU-2025-05-17_001057.zip deleted: Hardware/ECU/ECU-backups/ECU-2025-05-17_001712.zip new file: Hardware/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
    [ECU.csv, ECU.kicad_pcb]
2025-06-15 Update Parts & Cost
    Update Parts & Cost
    add breaks, breakpump, disk etc.
    add fule pump, filter, pressure regulator
    [Parts & Cost.ods]
2025-06-25 deleted: Hardware/ECU/ECU-backups/ECU-2025-05-17_134922.zip deleted: Hardware/ECU/ECU-backups/ECU-2025-05-18_153853.zip deleted: Hardware/ECU/ECU-backups/ECU-2025-05-18_155339.zip deleted: Hardware/E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
    [ECU-B_Cu.dxf, ECU-F_Adhesive.dxf, ECU-NPTH-drl_map.dxf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]
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2025-08-08 deleted: Hardware/ECU/ECU-backups/ECU-2025-05-20_150003.zip deleted: Hardware/ECU/ECU-backups/ECU-2025-05-27_155558.zip deleted: Hardware/ECU/ECU-backups/ECU-2025-05-27_174943.zip new file: Hardware/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
    [ECU-B_Cu.dxf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]
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2025-10-01 new file: Hardware/Abgasstopfen/Abgas-Stopfen v1.step new file: Hardware/Abgasstopfen/Skizze.dxf new file: Hardware/Abgasstopfen/Skizze.png deleted: Hardware/ECU/ECU-backups/ECU-2025-05-28_135321.zip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
    [Abgas-Stopfen v1.step, Parts & Cost.ods, Skizze.dxf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]
2025-12-19 new file: Hardware/Airbox/FB[1]-00-00.jpg new file: Hardware/Airbox/FB[1]-00-00.zip new file: Hardware/Airbox/IMG_4321.JPG new file: Hardware/Airbox/IMG_4328.JPG new file: Hardware/Airbox/airbox.stp 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
    [14429_0.stp, FB[1]-00-00.SLDPRT, FB[1]-00-00.x_t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]
2026-01-19 deleted: Hardware/ECU/ECU-backups/ECU-2025-05-27_235240.zip deleted: Hardware/ECU/ECU-backups/ECU-2025-05-28_135321.zip deleted: Hardware/ECU/ECU-backups/ECU-2025-05-28_140049.zip deleted: Hardware/E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
    [ECU.kicad_pcb, ECU.kicad_sch, Inputs.kicad_sch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]
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2026-04-30 Replace speeduino submodule with HasiKe fork, fix teensy.pretty path
    - Switch speeduino from speeduino/speeduino to HasiKe/speeduino
    - Fix teensy.pretty submodule path case mismatch (Hardware -> hardware)
    - Add ISL9V5036P3-F085 component library
    - Various ECU schematic updates
    [Comms.kicad_sch, Conntectors.kicad_sch, Crank-and-Cam.kicad_sch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]
2026-04-30 Dokumentation überarbeitet: professioneller, Dropbear v2, Klopfsensor
    - Alle Dokumente auf Deutsch vereinheitlicht
    - Emojis reduziert (nur Status-Checkmarks)
    - Arduino Mega 2560 durch Dropbear v2 / Teensy 4.1 ersetzt
    - Klopfsensor als geplantes Feature dokumentiert
    - TUNING.md: Erfundene Werte entfernt, nur allgemeine Prinzipien
    - HasiKe Speeduino Fork referenziert
    - Pfade korrigiert (hardware/ statt Hardware/)
2026-04-30 new file: "T\303\234V/Brembo_ABE_Bremsscheibe_Vorne_Schwimmend.pdf" renamed: hardware/Nockenwellen einstellen/Hayabusa Standarn Nochenwellen einstellen.md -> docs/Hayabusa Standarn Nochenwellen einst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
    [Airbox mit Ladeluftkühler V2.f3z, FB[1]-00-00.SLDPRT, FB[1]-00-00.x_t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]
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2026-08-26 new file: hardware/ECU/.step modified: hardware/ECU/Conntectors.kicad_sch modified: hardware/ECU/Drivers.kicad_sch modified: hardware/ECU/ECU.kicad_pcb modified: hardware/ECU/ECU.kicad_pro modified: 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
    [BOM-JLCPCB.csv, Conntectors.kicad_sch, Drivers.kicad_sch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]
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2026-08-28 Add design spec for exhaust-mic stereo audio recorder
    Two-channel high-SPL audio recorder for engine and exhaust sound,
    built around ESP32-S3 + PCM1861 instead of the earlier Teensy 4.1
    sketch.
    Design decisions and their basis:
    - IM73A135V01 analog MEMS (135 dBSPL AOP) replaces SPH0645LM4H,
    whose 120 dBSPL AOP would clip at the exhaust tip
    - PCM1861 with software PGA replaces INA1650 + OPA1662 + PCM1808;
    4.2 Vrms differential full scale removes the need for an attenuator
    - Buffer and local 2.8 V LDO in each mic head: datasheet limits the
    microphone to Cload <= 100 pF and VDD <= 3.0 V
    - PCM1861 as I2S master off a 24.576 MHz oscillator, MCU as slave
    - DS3231SN TCXO plus NTP plus LED/pi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
2026-08-28 Add exhaust-mic schematics: main board and mic head
    Complete schematic for the two-channel engine/exhaust audio recorder
    described in the design spec. Six sheets for the main board plus a
    separate project for the mic head, which is populated twice.
    Signal chain: IM73A135V01 analog MEMS (135 dBSPL AOP) with a local
    2.8 V LDO and buffer per head, over shielded twisted pair into a
    PCM1863 stereo ADC running as I2S master off a 24.576 MHz oscillator,
    recorded by an ESP32-S3-WROOM-1-N8R2 to microSD. DS3231SN TCXO plus a
    LED/piezo sync marker provide the timebase for aligning recordings with
    video.
    Schematics are generated from Python rather than drawn by hand, so the
    pin map and net names live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
    [01-power.kicad_sch, 02-analog.kicad_sch, 03-adc.kicad_sch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]
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2026-09-02 Add sensor module firmware
    STM32G474RBT6 firmware for the second board in hardware/ECU (rev 3.0-draft).
    Reads four MAX31855K exhaust thermocouples over SPI2, eight analog channels
    through ADC1 and ADC2 with DMA, drives the intercooler fan on PB0 and
    broadcasts everything to the Speeduino ECU over classic CAN at 500 kbit/s.
    The pin map and every scaling factor that follows from the schematic come from
    the rev 3.0 netlist. Note that the thermocouple chip selects are not in a
    running order on the board: IC2 carries thermocouple 3 and IC3 carries
    thermocouple 2.
    The fan control law runs locally on the hotter of the two intercooler water
    sensors, so it survives a CAN failure. The ECU can overri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
2026-09-02 Externe Werkzeuge aus dem Repository nehmen, README überarbeiten
    Die drei freerouting-JARs lagen mit zusammen 135 MB im Repository. Sie sind
    Fremdsoftware mit eigener Lizenz und gehören nicht dazu: jeder Clone musste
    sie mitziehen, und GitHub hat zwei davon als zu groß beanstandet. Sie sind
    jetzt ungetrackt und über .gitignore ausgeschlossen, lokal aber unberührt.
    Das Haupt-README beschrieb einen Stand, den es so nicht mehr gibt. Korrigiert
    und ergänzt:
    - Die Platine hat zwei Kupferlagen und misst rund 148 x 112 mm, nicht vier
    Lagen und 100 x 80 mm.
    - Einspritzung und Zündung laufen über einen MC33810 mit externen IGBTs,
    nicht über einzelne Low-Side-Treiber.
    - Sensor-Modul, Exh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
2026-09-03 Tune-Projekt Hayabusa-R3 aus den Serienkennfeldern erzeugen
    TunerStudio-Projekt für die Rev 3 (Board 57) auf der 1999er Gen 1 mit dem
    frühen 8-Zahn-Kurbelrad. VE- und Zündtabelle stammen aus den Serienkennfeldern
    in tune/setup/maps.ods (TPS-Map mit 120/205 skaliert, Leerlaufzellen auf 40,
    Zündung minus 3 Grad ab 25 % Last wegen 12:1), alles Übrige sind
    Erststart-Werte: Wasted COP und Semi-Sequential, Fixed Timing 10 Grad,
    Begrenzer 5500/6000, Dual Wheel 8 Zähne mit Nockenpuls, Trigger-Winkel 350
    unverifiziert, 257 cc/min Düsen, Serien-IAP-Sensor mit 10/142 kPa.
    Das Tune wird von tools/gen_tune.py erzeugt und gegen die INI validiert; die
    Projekt-INI ist eine Kopie der Fork-INI. Das RE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
